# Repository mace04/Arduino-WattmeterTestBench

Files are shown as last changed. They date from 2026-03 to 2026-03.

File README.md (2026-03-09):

# ESP32 Wattmeter Test Bench

A comprehensive motor test bench system built on ESP32, designed for measuring and analyzing the performance of electric motors in RC applications (propellers and EDF units). The system provides both local touchscreen interface and web-based remote control with real-time monitoring capabilities.

I had great problem connecting my HX711 sensor to ESP32 and make it work, so I decided to us an arduino that will read the weight sensor and send the readings to ESP via I2C. For more details see project in [mace04/Arduino-WeightSensor](https://github.com/mace04/Arduino-WeightSensor)

## Project Overview

This test bench measures voltage, current, power consumption, thrust, and monitors motor performance over time. It supports both manual throttle control and automated test sequences with configurable parameters. The dual-core ESP32 handles sensor acquisition and web services concurrently, making it ideal for precision motor testing.

**Key Features:**
- Real-time voltage, current, thrust, and power measurement
- Manual and automated testing modes
- TFT touchscreen interface with multiple screens
- Web-based configuration and monitoring
- Over-the-air firmware updates
- Dual-core processing for responsive operation
- Persistent storage for settings and test profiles

## Main Capabilities

### 1. Motor Testing Modes

#### Manual Mode
- Direct throttle control from analog input or TFT interface
- Real-time sensor data display (voltage, current, thrust, power)
- Energy consumption tracking (mAh)
- Start/stop control with safety interlocks
- Emergency throttle cut via hardware switch

#### Auto Test Mode
- Automated test sequences with 5 phases:
  - Phase 0: Ramp up from 0% to 50% throttle (configurable duration)
  - Phase 1: Hold at 50% throttle (configurable duration)
  - Phase 2: Ramp up from 50% to 100% throttle
  - Phase 3: Hold at 100% throttle
  - Phase 4: Ramp down from 100% to 0%
- Configurable warm-up and phase durations
- Automatic data logging throughout test

### 2. Sensor Measurements

- **Voltage**: 12-bit ADC with calibration and running average filter
- **Current**: 12-bit ADC with calibration and running average filter  
- **Thrust**: I2C weight sensor bridge with configurable scale and offset
- **Power**: Calculated from voltage × current
- **Energy Consumption**: Accumulated mAh over time
- **Elapsed Time**: Test duration timer (mm:ss format)

#### Weight Sensor I2C Protocol
- **Companion Device Project**: [mace04/Arduino-WeightSensor](https://github.com/mace04/Arduino-WeightSensor)
- **I2C Address**: `0x11`
- **Pins**: SDA=`GPIO26`, SCL=`GPIO25`
- **Read Payload**: 4-byte `float` (weight in grams)
- **Calibration Payload**: 8-byte packet `{ float scale, int32_t offset }`
- **Tare Reset Command**: single-byte command `0xA5` (`I2C_CMD_TARE_RESET`)
- **Read Fallback Behavior**: if read payload is incomplete/invalid, firmware returns the last known valid weight

See detailed protocol documentation: [WeightI2Cprotocol.md](WeightI2Cprotocol.md)

### 3. Display Interface (TFT Touchscreen)

- **Main Menu**: Access manual test, auto test, about screen, and profile selection
- **Motor Test Screen**: Real-time data panels showing all sensor readings
- **Calibration Mode**: Guided calibration for voltage, current, and thrust sensors
- **Scale Calibration**: Separate mode for calibrating the load cell
- **Message Boxes**: User notifications and error messages

### 4. Web Interface

Accessible via WiFi network or ESP32 hotspot (fallback mode)

#### Pages:
- **Home (`/`)**: Main menu with navigation links and live event log
- **Settings (`/settings`)**: Configure all system parameters
- **Test Profile (`/testprofile`)**: Define motor specifications
- **Internal Storage (`/spiffs`)**: Browse and view SPIFFS files
- **SD Card (`/sdcard`)**: Access SD card files (if available)
- **Firmware Update (`/update`)**: OTA firmware and filesystem updates

#### Real-time Features:
- **Server-Sent Events (`/events`)**: Live debug, error, and log messages
- **Streaming (`/stream`)**: Real-time sensor data feed
- **File Download**: Download files from SPIFFS or SD card

### 5. Configuration & Settings

All settings stored in `/settings.json` on SPIFFS:

- **WiFi**: SSID and password
- **Voltage Sensor**: Sensitivity (volts per point) and offset
- **Current Sensor**: Sensitivity (volts per point) and offset
- **Thrust Sensor**: Scale and offset values
- **Safety Limits**: Maximum current and thrust thresholds
- **Test Parameters**: Phase duration and warm-up duration

### 6. Safety Features

- **Throttle Cut Switch**: Hardware emergency stop (GPIO 22)
- **Pre-start Checks**: Validates throttle at zero before starting
- **Error Handling**: Comprehensive error messages via web and display
- **I2C Read Validation**: Guards against short/invalid payloads and falls back to last valid reading

## ESP32 GPIO Pin Mapping

### Display & Touch (SPI)
| Function | GPIO | Description |
|---|---|---|
| TFT_MISO | 19 | SPI MISO |
| TFT_MOSI | 23 | SPI MOSI |
| TFT_SCLK | 18 | SPI Clock |
| TFT_CS | 5 | TFT Chip Select |
| TFT_DC | 2 | Data/Command Select |
| TFT_RST | 4 | TFT Reset |
| TOUCH_CS | 15 | Touch Chip Select |
| TOUCH_IRQ | 13 | Touch Interrupt (optional) |

### SD Card (Shared SPI)
| Function | GPIO | Description |
|---|---|---|
| SD_CS | 17 | SD Card Chip Select |
| SD_MOSI | 23 | SPI MOSI (shared) |
| SD_MISO | 19 | SPI MISO (shared) |
| SD_SCLK | 18 | SPI Clock (shared) |

### Sensors (ADC)
| Function | GPIO | ADC Channel | Description |
|---|---|---|---|
| VOLTAGE_SENSOR_PIN | 35 | ADC1_CH7 | Battery voltage measurement |
| CURRENT_SENSOR_PIN | 34 | ADC1_CH6 | Current sensor input |
| THROTTLE_CONTROL_PIN | 36 | ADC1_CH0 | Manual throttle input |

### Motor Control & Sensors
| Function | GPIO | Description |
|---|---|---|
| ESC_OUTPUT_PIN | 21 | PWM output to ESC (1000-2000μs) |
| THROTTLE_CUT_PIN | 22 | Emergency stop switch (INPUT_PULLUP) |
| WEIGHT_I2C_SDA_PIN | 26 | I2C SDA for weight sensor bridge |
| WEIGHT_I2C_SCL_PIN | 25 | I2C SCL for weight sensor bridge |

### Voltage Divider Details
- **Voltage Sensor**: R1=14.98kΩ, R2=2.14kΩ (ratio ~105.295)
- **Current Sensor**: R1=14.86kΩ, R2=13.59kΩ (ratio ~240.350)

## Web Interface Details

### Main Menu (`/` or `/index`)
- Navigation buttons to all major functions
- Real-time event log at bottom (debug/error/info messages)
- Clean grid layout with CSS styling

### Settings Page (`/settings`)
Organized into sections:
- **WiFi Settings**: SSID and password
- **Voltage Sensor**: Sensitivity and offset calibration
- **Current Sensor**: Sensitivity, offset, and maximum current
- **Thrust Sensor**: Scale, offset, and maximum thrust
- **Test Settings**: Phase duration and warm-up time

Settings are saved to SPIFFS and persist across reboots. Success banner shows after saving.

### Test Profile Page (`/testprofile`)
Configure motor under test:
- **Motor Name**: Up to 50 characters (alphanumeric + spaces)
- **Motor Type**: Propeller or EDF (radio button)
- **Propeller Diameter**: 0-150 inches
- **Propeller Pitch**: 1-20 inches (hidden if EDF selected)
- **Battery Cells**: 1-9 cells

Profile saved to `/testprofile.json` on SPIFFS.

### Internal Storage (`/spiffs`)
- Lists all files in SPIFFS filesystem
- Radio buttons for file selection
- View button displays file content (JSON pretty-printed)
- Text area shows file contents

### Firmware Update (`/update`)
- Upload firmware binary (`.bin`)
- Upload filesystem image (SPIFFS)
- Upload type selector: `firmware` or `filesystem`
- Settings automatically backed up and restored during filesystem updates
- Automatic reboot after successful update

### File Download (`/getfile`)
Query parameters:
- `filename`: File to download
- `from`: Either `spiffs` or `sdcard`

### Real-time Streaming (`/stream`)
Returns JSON with current sensor readings:
```json
{
  "voltage": 12.34,
  "current": 5.67,
  "thrust": 890,
  "power": 70,
  "consumption": 123,
  "time": "02:15",
  "throttle": 75
}
```

### Server-Sent Events (`/events`)
Three event types:
- `debug`: Debug messages from system
- `error`: Error notifications
- `log`: General log messages

JavaScript on web pages subscribes to these for live updates.

## Known Issues

### 1. Running Average Not Fully Implemented
**Location**: [sensors.cpp](src/sensors.cpp#L85-L112)

The `readVoltageGpio()` and `readCurrentGpio()` functions have running average code that is commented out with an early return statement. The averaging arrays are allocated but not used.

```cpp
// Current code returns immediately:
return vOut;
// Dead code below calculates average
```

**Impact**: Sensor readings may be noisier than intended.

**Fix**: Remove early returns and enable the averaging logic.

### 2. I2C Weight Sensor Startup Calibration Disabled
**Location**: [sensors.cpp](src/sensors.cpp)

The initial calibration send in `initSensors()` is currently commented out. This means startup may rely on previously retained calibration state in the I2C weight bridge.

**Impact**: Scale/offset may not be explicitly initialized at boot.

**Fix**: Re-enable startup `sendWeightCalibration(settings.getThrustScale(), settings.getThrustOffset())` if deterministic startup calibration is required.

### 3. Static Variables in Auto Test State Machine
**Location**: [motorControl.cpp](src/motorControl.cpp#L143-L211)

Each case in the auto test state machine uses `static bool stageXLogged` variables that are never reset. If auto test is run multiple times, debug messages won't appear after the first run.

**Impact**: Reduced debugging visibility on subsequent auto tests.

**Fix**: Reset static flags in `reset()` or `startAuto()` methods.

### 4. Unreachable Code After Return Statements
**Location**: [sensors.cpp](src/sensors.cpp#L90-L98)

Several functions have unreachable code after return statements (running average calculations).

**Impact**: Compiler warnings and misleading code.

**Fix**: Remove early returns or delete unreachable code.

### 5. Settings Restoration During Filesystem Update
**Location**: [WebServerHandler.cpp](src/WebServerHandler.cpp#L318-L360)

The settings backup/restore during filesystem updates loads settings into RAM but doesn't properly handle the case where SPIFFS is reformatted during update.

**Impact**: Settings may be lost during filesystem updates.

**Fix**: Backup to a file outside SPIFFS or implement more robust restoration.

### 6. SD Card Not Fully Integrated
**Location**: Multiple files

SD card is initialized in pins and main.cpp includes SD.h, but actual SD card functionality appears incomplete. No route handler for `/sdcard` endpoint exists.

**Impact**: SD card file browsing doesn't work from web interface.

**Fix**: Implement `handleFileAccess()` function for SD card access.

## TODO List

### High Priority
- [ ] Fix running average implementation for voltage/current sensors
- [ ] Implement SD card file browser web endpoint (`/sdcard`)
- [ ] Add data logging to SD card during tests (CSV format)
- [ ] Reset static flags in auto test state machine
- [ ] Remove unreachable code after early returns

### Medium Priority
- [ ] Add graphing capabilities to web interface (Chart.js or similar)
- [ ] Implement test result export functionality
- [ ] Add WiFi configuration portal (captive portal on first boot)
- [ ] Create calibration wizard with step-by-step instructions
- [ ] Add authentication to web interface (username/password)
- [ ] Implement motor efficiency calculations (thrust/watt)

### Low Priority
- [ ] Add support for multiple test profiles (save/load by name)
- [ ] Create comparison view for multiple test runs
- [ ] Add temperature sensor monitoring (motor and ESC)
- [ ] Implement RPM measurement (optical sensor)
- [ ] Add battery level estimation (LiPo cell count detection)
- [ ] Create mobile-friendly responsive web design
- [ ] Add WebSocket for bidirectional communication (replace SSE)

### Code Quality
- [x] Document I2C weight protocol in [WeightI2Cprotocol.md](WeightI2Cprotocol.md)
- [ ] Add unit tests for calculation functions
- [ ] Improve error handling and user feedback
- [ ] Document web API endpoints (OpenAPI/Swagger)
- [ ] Add comments to complex functions
- [ ] Implement proper settings validation

### Documentation
- [ ] Create wiring diagram with pin connections
- [ ] Add calibration procedure documentation
- [ ] Write user manual for web interface
- [ ] Document auto test sequence in detail
- [ ] Add troubleshooting guide
- [ ] Create video tutorials

## Dependencies

### PlatformIO Libraries
```ini
lib_deps = 
    ArduinoJson
    bodmer/TFT_eSPI @ ^2.5.43
    paulstoffregen/XPT2046_Touchscreen
    madhephaestus/ESP32Servo
    esp32async/AsyncTCP
    esp32async/ESPAsyncWebServer
```

### Platform
- Framework: Arduino
- Platform: Espressif32
- Board: ESP32 DOIT DevKit v1
- Monitor Speed: 115200 baud

### Partition Scheme
Custom partition: `default_1.5MBapp_spiffs768KB.csv`
- App: ~1.5 MB
- SPIFFS: 768 KB

## File Structure
```
ESP32-WattmeterTestBench/
├── src/                          # Source files
│   ├── main.cpp                  # Main program entry
│   ├── motorControl.cpp          # ESC and throttle control
│   ├── sensors.cpp               # Sensor reading functions
│   ├── Settings.cpp              # Settings management
│   ├── WebServerHandler.cpp      # Web server and API
│   ├── TftMainMenu.cpp           # Main menu screen
│   ├── TftMotorTest.cpp          # Test screen UI
│   ├── TftCalibrate.cpp          # Calibration UI
│   └── [other TFT screens]
├── include/                      # Header files
│   ├── motorControl.h
│   ├── sensors.h
│   ├── Settings.h
│   ├── WebServerHandler.h
│   ├── tft_config.h
│   └── [other headers]
├── data/                         # Web server files (SPIFFS)
│   ├── index.html                # Main menu page
│   ├── settings.html             # Settings page
│   ├── testprofile.html          # Test profile page
│   ├── spiffs.html               # File browser
│   ├── update.html               # OTA update page
│   ├── style.css                 # Shared CSS
│   ├── common.js                 # Shared JavaScript
│   └── index.js
├── schematics/                   # Hardware design files
│   └── WattThrustMeter.fzz       # Fritzing schematic
├── platformio.ini                # PlatformIO configuration
├── increment_version.py          # Auto version script
├── version.txt                   # Current version
├── ESP32 pinout mapping.md       # Pin documentation
└── README.md                     # This file
```

## Getting Started

1. **Hardware Setup**: Wire sensors and display according to pin mapping
2. **Flash Firmware**: Use PlatformIO to build and upload
3. **Upload Filesystem**: Upload SPIFFS image with web files
4. **Configure WiFi**: Edit settings via web interface or serial
5. **Calibrate Sensors**: Use calibration mode (hold throttle cut during boot)
6. **Run Tests**: Select manual or auto mode from TFT or web interface

## License

[Add your license here]

## Author

[Add your name/contact here]

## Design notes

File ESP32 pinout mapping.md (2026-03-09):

### **ESP32 Pin Mapping**
| **Panel Pin** | **ESP32 Pin**  | **Function** | **Purpose** |
|---|---|---|---|
| **LCD_RST** | GPIO16 | Reset | Resets the TFT display |
| **LCD_CS (YP)** | GPIO5 | Chip Select / Y+ (ADC) | Activates TFT module / Y-axis touch input |
| **LCD_RS (XM)** | GPIO4 | Data/Command / X- | Selects between command/data / X-axis touch control |
| **LCD_WR** | GPIO17 | Write Strobe | Signals a write operation to the TFT |
| **LCD_RD** | GPIO21 | Read Strobe | Signals a read operation from the TFT |
| **5V** | 5V | Power | Powers the display |
| **GND** | GND | Ground | Common ground connection |
| **3V3** | 3.3V | Power | Alternative power supply if required |
| **LCD_D0 (XP)** | GPIO12 | Parallel Data Bus / X+ | Pixel data transfer / X-axis touch input |
| **LCD_D1 (YM)** | GPIO13 | Parallel Data Bus / Y- | Pixel data transfer / Y-axis touch control |
| **LCD_D2** | GPIO26 | Parallel Data Bus | Pixel data transfer |
| **LCD_D3** | GPIO25 | Parallel Data Bus | Pixel data transfer |
| **LCD_D4** | GPIO27 | Parallel Data Bus | Pixel data transfer |
| **LCD_D5** | GPIO14 | Parallel Data Bus | Pixel data transfer |
| **LCD_D6** | GPIO33 | Parallel Data Bus | Pixel data transfer |
| **LCD_D7** | GPIO32 | Parallel Data Bus | Pixel data transfer |
| **SD_SS** | GPIO2 | SD Card Chip Select | Activates SD card module |
| **SD_DI (MOSI)** | GPIO23 | SPI MOSI | Sends data to SD card |
| **SD_DO (MISO)** | GPIO19 | SPI MISO | Receives data from SD card |
| **SD_SCK** | GPIO18 | SPI Clock | Synchronizes SD card data transfer |
| **Voltage Sensor**  | GPIO34 | Analog Input (ADC1) | Reads voltage measurements |
| **Current Sensor**  | GPIO35 | Analog Input (ADC1) | Reads current measurements |
| **Throttle Control**| GPIO39 | Analog Input (ADC1) | Reads throttle position |
| **Throttle Cut** | GPIO15 | Digital Input (Unique) | Emergency stop signal |
| **ESC Output (PWM)**| GPIO3 | PWM Output (Unique) | Controls motor speed via ESC |
| **HX711 - DT** | GPIO22 | Weight Sensor Data | Weight measurement input |
| **HX711 - SCK** | GPIO1 | Weight Sensor Clock | Weight sensor clock |

Define mapping to ESP32 devkit v1 for the Starbun TFT LCD Color Touch Panel 3.5" TFT LCD Module 480x320 with the following pins on the panel
    * LCD_RST
    * LCD_CS
    * LCD_RS
    * LCD_WR
    * LCD_RD
    * 5V
    * GND
    * 3V3
    * LCD_D0
    * LCD_D1
    * LCD_D2
    * LCD_D3
    * LCD_D4
    * LCD_D5
    * LCD_D6
    * LCD_D7
    * SD_SS
    * SD_DI
    * SD_DO
    * SD_SCK
Also, the touchscreen uses the below pins from the above defined pins
    * LCD_CS as YP
    * LCD_RS as XM
    * LCD_D1 as YM
    * LCD0 as XP
Finally add the following requirements in the mapping
    * Analog input for voltage sensor
    * Analog input for current sensor
    * Analog input for throttle control
    * Digital input for throttle cut
    * PWM output for ESC control
    * DT for HX711 sensor
    * SCK for HX711 sensor

Define mapping to ESP32 devkit v1 for the 3.5 inch LCD TFT touch display with ili9488 chip Binghe 3.5 inch LCD display touch module with the following pins on the panel
    * VCC
    * GND 
    * CS
    * RESET
    * C/C
    * SDI
    * SCK
    * LED 
    * SDO(MISO)
    * T_CLK
    * TOUCH_CS
    * T_DIN
    * T_OUT
    * TOUCH_IRQ
    * SD_CS
    * SD_MOSI
    * SD_MISO
    * SD_SCK
Also add the following requirements in the mapping
    * Analog input for voltage sensor
    * Analog input for current sensor
    * Analog input for throttle control
    * Digital input for throttle cut
    * PWM output for ESC control
    * DT for HX711 sensor
    * SCK for HX711 sensor

# Sensors 
what is the best board_build.partitions to use for the following
    * Factory app 2MB
    * OTA app 2MB
    * SPIFFS 1.5MB

Create a sensors include file with the following

    Create a function readVoltageSensor to read voltage from the voltage sensor in GPIO34 with the following requirements
        * the pin is connected to a voltage divivder with R1 of 15K and R2 of 2.2K
        * use a running average to smooth readings

    Create a function readCurrentSensor to read voltage from the voltage sensor in GPIO35 with the following requirements
        * the sensor is connected to a ACS758KCB-150B-PFF-T
        * use a running average to smooth readings

    Create a function resetWeightSensor that resets the weight sensor usinh HX711

    Create a function readWeightSensor that reads weight in grams from the weight sensor HX711

Create an motorControl class with the following
    * A function setThrottleCut that sets a global variable for the throttle cut based on a boolean parameter
    * A function setThrottle with the following
        * read the value of throttle control from pin 39
        * if the throttle cut is not set sets the corresponding PWM setting to the esc output in pin 3
        * if the throttle cut is set esc must be set to no throttle
        * returns the throttle control value from pin 39 as a percent
    * create a second function setThottle to set the thottle using a parameter percent value and not from a reading from the THROTTLE_CONTROL_PIN with the rest of requirments the same as the original function
    * a function to get the value fo the throttle cut

Create a new include file to handle settings with the following:
    * The following key value pairs should be defined:
        * SSID name and password as string
        * volts per point for votlage sensor as double with initial value of 0.12790
        * voltage offset as double with initial value of 0.00
        * volts per point for current sensor as double with initial value of 0.02
        * current offset as double with a initial value of - 2.5
        * thrust offset as double with initial value of 0.00
        * maximum current as int with initial value of 100
        * maximum thrust as int with initial value of 4900
        * test phase duration in seconds as int with initial value of 45
    * ablity to read key value pair settings from SPIFFS and return with correct data type for the setting
    * ability to write key value pair settings to SPIFFS usng a correct data type for the setting
    * implement all getters and setters
    * the SPIFF settings files not be opened everytime a read is happening
    * the SPIFF settings file should be refreshed everytime a setter is called
    * include any changes required to platforio.ini for lib_deps

Create a new include file with the following:
    * A function to initialise WiFi connection. If wifi is not connected a hotspot should be created to direct to settings endpoint
    * a function to initialise web server endpoints using the WebServer class for settings, ota, file access to sd card files and realtime streaming of sensor readings. 
    * a function to handle GET settings that will respond with the settings.html from SPIFFS to the connected client
    * a function to handle POST settings. all setting values should be saved to the settings variable in main.cpp
    * a function to hanlde OTA firmware update
    * a function get all files from the SD Card and respond with a full list to the connected client
    * a function to stream sensor readings from sensors.h for voltage, current, weight and cacluated watts in csv to the connected client
    * include any changes required to platforio.ini for lib_deps

create a settings.html with the following requirements
    * use style.css
    * use index.js
    * Title heading on the top of the page of Motor Test Settings 
    * Display settings label and input for each setting defined to be replaced by the handleGetSettings function
    * All string input should be of type text
    * Password input should be of type password
    * All numeric inputs should be of type number
    * All labels should be displayed above the inputs in separate row
    * Settings should be displayed in 2 columns

using settings.html as a template and style.css as a stylsheet, create index.html to display a main menu with the following buttons
    * Settings that links to settings.html
    * Update Firmware that links to update.html
    * SD Card that links to sdcard.html
    * Internal Storage that links to spiffs.html

create an update.html file with the following requirements
    * use style.css
    * Title heading on the top of the page of update firmware
    * Request client to select and input a firmware BIN file 
    * submit with value update

change WebServerHandler files to add capabilitie for OTA firmware update with the following
    * Handle for a GET update endpoint to display the update.htm to connected client
    * Handle for as POST update endpoint that will 
        * be able to and httpupload of the file 
        * when upload is finished perform an update of firmware 
        * determine if the update was a success or failure
        * restart the ESP 

Create a class TftMainMenu for a Starbun Parallel 3.5" TFT LCD Colour Touch Panel with the follwing requirements 
    * Use TFT_eSPI and XPT2046_Touchscreen libraries
    * For UX
        * Background colour set to NAVY
        * Menu options should be buttons that can be selected by touch
        * A menu option for Start Manual Test
        * A menu option for Start Auto Test
        * A menu option for About
        * All buttons should be centered vertically and horizontally within the screen
        * Button text should be centered within the boundaries of the button
        * Button colour should be green with an black outline
        * Buttons colour should changed to red when pressed
        * Button corners should be rounded
    * The class should have the following capabilities
        * accept tft panel and touchscreen as parameters in contructor
        * Determining menu selection should be in separate function 
        * Ability  to change to a different screen using the TftScreenMode enum when a button is pressed. This should instruct the core0Task to call the init method of a different class
        * Introduce a debounce capability to detect continuous press on buttons

Create a class TftUpdate class for a 3.5" TFT LCD Colour Touch Panel with the follwing requirements 
    * Use TFT_eSPI and XPT2046_Touchscreen libraries
    * Accept tft panel as parameter in contructor
    * For UX
        * Background colour set to NAVY
        * A rounded red box appears in the center of the screen 
        * The text "Updating Firmware" is displayed 
        * The text displayed in the box should be centered withing the boundaries of the box

Using TftMainMenu as a template create a class TftAbout for a 3.5" TFT LCD Colour Touch Panel with the following requirements 
    * Use TFT_eSPI and XPT2046_Touchscreen libraries
    * For UX
        * Background colour set to NAVY
        * All text set to white
        * Display the title "Motor Testbench" in bold
        * Display Firmware version
        * Display WiFi name
        * Display IP Address
        * Screen should be split into 6 column and display label in 2nd column as left aligned and value in column 5th column as right aligned
    * The class should have the following capabilities
        * accept tft panel and touchscreen as parameters in contructor
        * The init method should chip select PANEL at the start and TOUCH at the end using the setCS?() function in tft_config files
        * the handleTouch method should check both the TOUCH_IRQ interrupt pin and ts.touch() for a touch  
        * TftAbout should be displayed when the About button in TftMainMenu is pressed
        * TftAbout should display TftMainMenu when any touch is detected anywhere inh the screen        

Using TftMainMenu as a template create a class TftMotorTest for a 3.5" TFT LCD Colour Touch Panel with the following requirements 
    * Use TFT_eSPI and XPT2046_Touchscreen libraries
    * For UX
        * Background colour set to NAVY
        * Create a ribbon on the top in DARKCYAN 40px in height to display the below buttons in green with black text for enabled buttons and grey with white text for diabled buttons and rounded corners
            * A Start button to be enabled on the left side of the screen
            * A Stop button to be disabled on the left side of the screen
            * A Reset button to be enabled on the left side of the screen
            * An Exit button to be enabled on the right side of the screen
        * Create a rectangular at the bottom of the screen in black that spans accross the length and is 30px height as a throttle indicator with the following details:
            * Display the value of throttle as a percent value in White text that is updated everytime the throttle is changed
            * As the throttle increases the rectangular bos is filled from left to right in green between 0% and 49%, amber between 50% and 84% and red between 85% and 100%
        * Between the top ribbon and the bottom throttle indicator split the screen into 3 columns and 2 rows to display panels in yellow with rounded conrners for Volts, Current in amps, Thrust in gr, Power in watts, Consumption in mAh and Time in mm:ss. Each pannel will be displayed as:
            * Recangular with rounded corners 
            * Background colour of yellow with black text
            * Top left of the pannel should display the value type
            * Bottom of pannel should display the value units centered within the boundaries of the pannel
            * Middle of pannel should display the value read in bigger fonts than the other two and updated every time the value changes.
    * The class should have the following capabilities
        * Define enabled and disabled colours for buttons
        * Define state of buttons
        * Accept tft panel, touchscreen and MANUAL or AUTO enum as test type as parameters in contructor
        * An init method to draw the full screen
        * A method to draw buttons with proper colours depending on their state
        * A method to change the state of the button and their colours when
        * A handler to update values on the panels and throttle that is called by the main task in main.cpp every 500ms
        * A method to handleTouch that will the following:
            * Call screenChangeCallback only when Exit button is preased to change to the Main Menu
            * Ignores press of disabled buttons
            * When Start button is pressed, the button becomes disabled and the Stop button is enabled
            * When Stop button is pressed, the button is disabled and the Start button is enabled
            * When Reset button is pressed the Start button is enabled and the Stop button is disabled
            * The Start, Stop and Rest buttons have a private method each to execute code

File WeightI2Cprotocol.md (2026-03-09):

# Weight Sensor I2C Protocol

This document defines the I2C protocol used between the ESP32 firmware and the external weight sensor bridge device.

Companion I2C device implementation: https://github.com/mace04/Arduino-WeightSensor

## Overview

- **Bus mode**: ESP32 is I2C **master**
- **Device address**: `0x11` (`WEIGHT_I2C_ADDRESS`)
- **ESP32 pins**:
  - `SDA = GPIO26` (`WEIGHT_I2C_SDA_PIN`)
  - `SCL = GPIO25` (`WEIGHT_I2C_SCL_PIN`)
- **I2C clock**: `100 kHz`

## Data Types and Endianness

- Floating point values are transmitted as **32-bit IEEE-754 float**.
- Integer offset is transmitted as **signed 32-bit integer** (`int32_t`).
- Multi-byte values are sent as raw in-memory bytes from the ESP32 side.
- Both ends must use compatible byte order and type sizes.

## Message Types

## 1) Weight Read (ESP32 -> Device, then Device -> ESP32)

### Request
ESP32 requests 4 bytes:

- `Wire.requestFrom(0x11, 4)`

### Response payload (4 bytes)

```text
Byte 0..3: float weight_grams
```

### Firmware behavior on receive

- If exactly 4 bytes are returned and value is finite: cache and return new weight.
- If byte count is wrong, stream underruns, or float is non-finite:
  - generate error event (throttled by warning flag)
  - return last known valid weight
  - if no valid value has ever been received, return `0`

## 2) Calibration Write (ESP32 -> Device)

### Purpose
Set calibration parameters used by the weight bridge.

### Payload (8 bytes)

```text
Byte 0..3: float scale
Byte 4..7: int32_t offset
```

### Used by firmware

- `calibrateWeightSensor()` sends default calibration:
  - `scale = 1.0f`
  - `offset = 0`

## 3) Tare Reset Command (ESP32 -> Device)

### Purpose
Request a tare/reset action from the weight bridge.

### Command byte

- `I2C_CMD_TARE_RESET = 0xA5`

### Payload

```text
Byte 0: 0xA5
```

### Used by firmware

- `resetWeightSensor()` sends this command as a single-byte I2C transmission.

## Error Handling Expectations

The device should:

- Respond to read requests with exactly 4 bytes when data is available.
- Gracefully handle malformed/unexpected calibration writes.
- Accept and process `0xA5` tare command idempotently when possible.

The ESP32 firmware currently:

- Validates response length and float sanity (`isfinite`).
- Emits error events on communication/payload failures.
- Uses last-known-value fallback to avoid UI/stream glitches when reads fail intermittently.

## Reference Implementation Mapping

- Protocol constants and declarations: `include/sensors.h`
- I2C send/read logic: `src/sensors.cpp`
  - `sendWeightCalibration(float, int32_t)`
  - `readWeightSensor()`
  - `resetWeightSensor()`

## Suggested Device-Side Contract

For best interoperability, implement the slave-side behavior as:

1. On write of 8 bytes: parse as `{scale, offset}` and apply calibration.
2. On write of 1 byte `0xA5`: perform tare/reset.
3. On master read request of 4 bytes: return latest weight as float grams.
4. Ensure response generation is quick and non-blocking.

## Versioning Note

If protocol changes are introduced later (new commands, CRC, sequence numbers), add a version byte or command frame format to maintain backward compatibility.

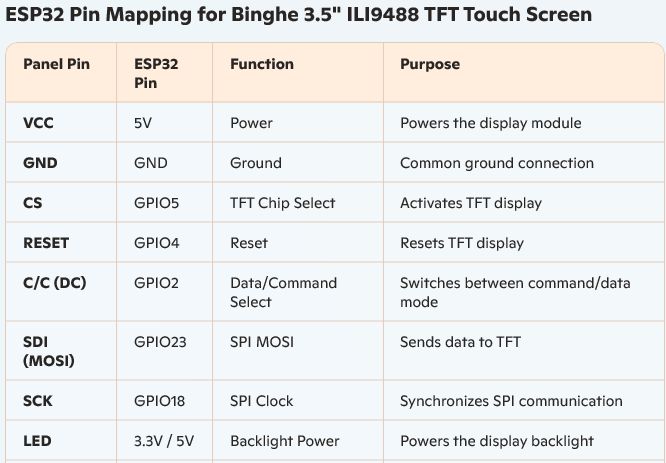
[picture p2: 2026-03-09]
schematics/ESP32 Pin Mapping for Binghe 3.5 ILI9488 TFT Touch Screen.png

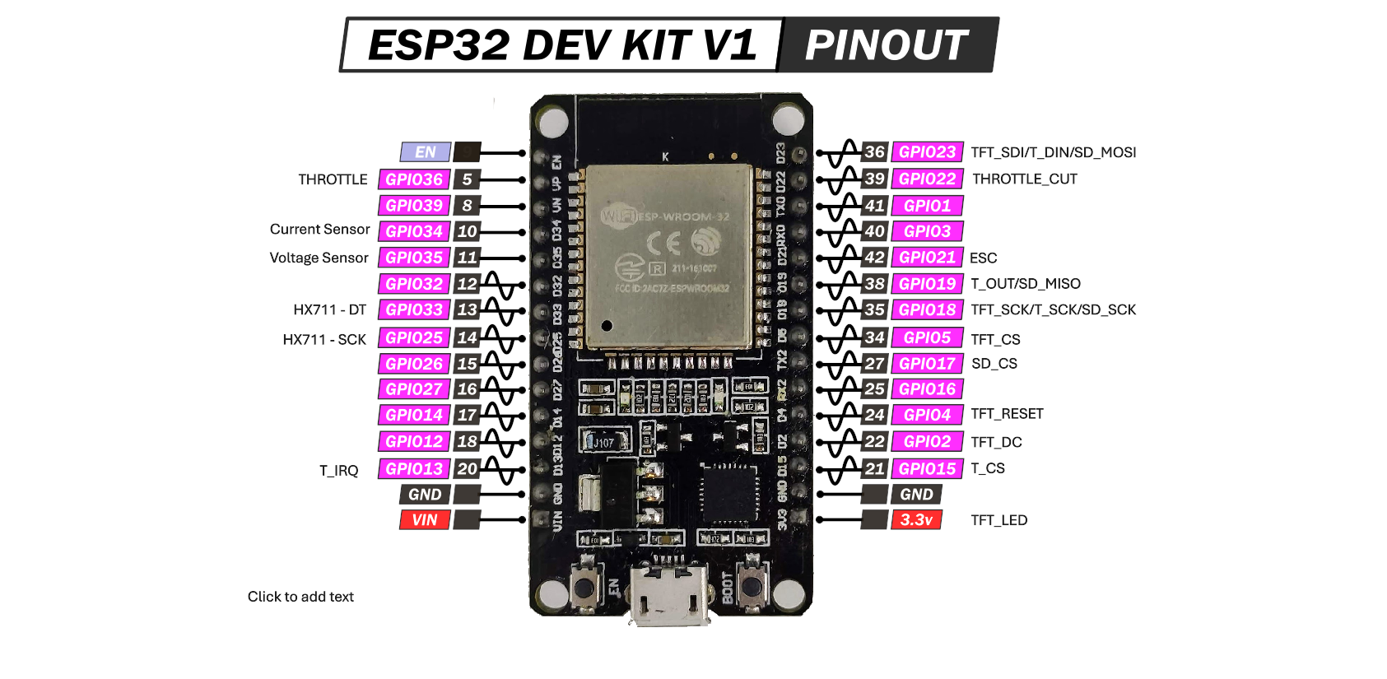
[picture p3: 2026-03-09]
schematics/ESP32-DOIT-DEV-KIT-v1-pinout.png

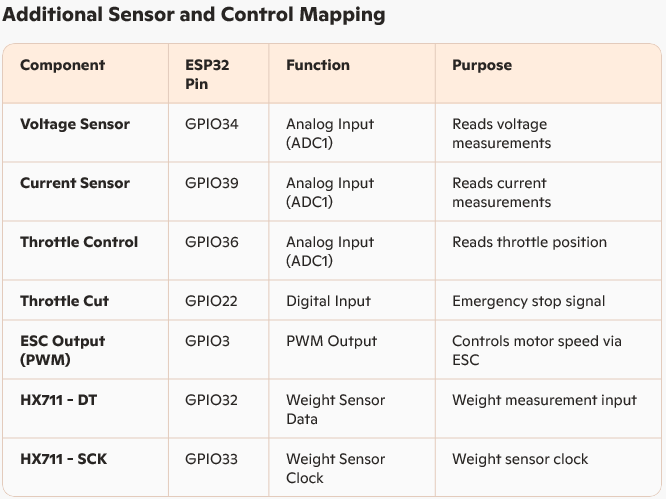
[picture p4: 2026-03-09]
schematics/Additional Sensor and Control Mapping.png

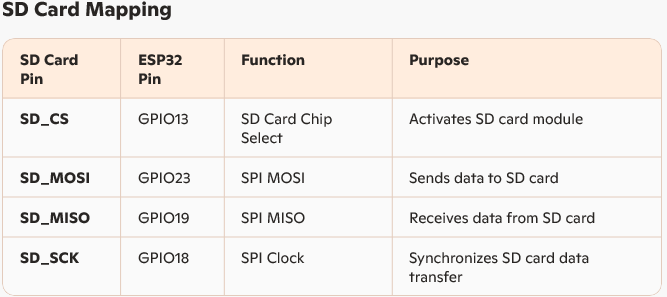
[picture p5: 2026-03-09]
schematics/SD Card Mapping.png

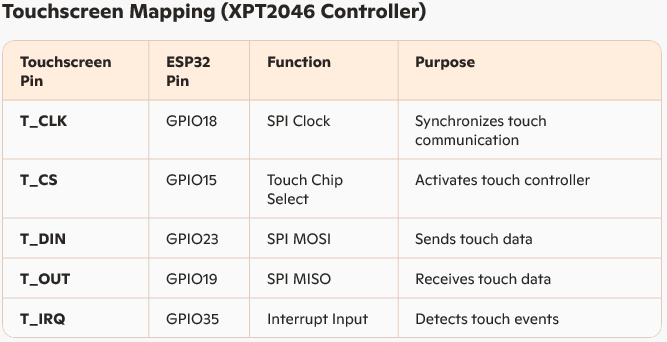
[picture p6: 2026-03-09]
schematics/Touchscreen Mapping (XPT2046 Controller).png

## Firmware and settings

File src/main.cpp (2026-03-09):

#include <Arduino.h>
#include <SD.H>
#include "soc/rtc.h"
#include "sensors.h"
#include "motorControl.h"
#include "Settings.h"
#include "WebServerHandler.h"
#include "tft_config.h"
#include "TftMainMenu.h"
#include "TftAbout.h"
#include "TftMotorTest.h"
#include "TftCalibrate.h"
#include "TftCalibrateScale.h"
#include "TftMessageBox.h"
#include <WiFi.h>

void screenChangeCallback(TftScreenMode screenMode);

Settings settings; // Create an instance of the Settings class
MotorControl motorControl; // Create an instance of the MotorControl class
TFT_eSPI tft = TFT_eSPI();
XPT2046_Touchscreen ts(TOUCH_CS, TOUCH_IRQ); // Touchscreen instance
TftScreenMode currentScreen = MAIN_MENU;
struct Profile testProfile = {"",0,0,0};

float voltage = 0.0; // Variable to store voltage reading
float current = 0.0; // Variable to store current reading
int thrust = 0; // Variable to store thrust reading
int power=0; // Variable to store power reading
float mAh = 0.0; // Variable to store accumulated mAh
bool enterCalibrationMode = false; // Flag to enter calibration mode in Setup
bool calibrateScale = false; // Flag to calibrate ESC in Setup


// Task handles
TaskHandle_t core0TaskHandle = NULL;
TaskHandle_t core1TaskHandle = NULL;

TftMainMenu tftMainMenu(tft, ts, screenChangeCallback);
TftAbout tftAbout(tft, ts, screenChangeCallback);
TftMotorTest tftMotorTest(tft, ts, screenChangeCallback);
TftCalibrate tftCalibrate(tft, ts);
TftCalibrateScale tftCalibrateScale(tft, ts);

// Callback function to handle screen changes
void screenChangeCallback(TftScreenMode screenMode) {
    currentScreen = screenMode;
    if (screenMode == MAIN_MENU) {
        tftMainMenu.init();
    } else if (screenMode == ABOUT) {
        tftAbout.init();
    } else if (screenMode == MANUAL_TEST){
        tftMotorTest.init(MANUAL);
    }
    else if (screenMode == AUTO_TEST){
        tftMotorTest.init(AUTO);
    }
}

// Task running on Core 0
void core0Task(void *parameter) {
    while (true) {
        handleWebServer(); // Handle web server requests
        motorControl.handleControls(); // Handle manual controls
        if (motorControl.isRunning()) {
            if (motorControl.getRunningMode() == MotorControl::RunningMode::AUTO) {
                motorControl.handleAutoTest(); // Handle auto test
            }
            tftMotorTest.Voltage = readVoltageSensor(); // Read voltage sensor
            tftMotorTest.Current = readCurrentSensor(); // Read current sensor
            tftMotorTest.Thrust = readWeightSensor(); // Read thrust sensor
            tftMotorTest.Power = calculatePower(voltage, current); // Calculate power in watts
            tftMotorTest.Consumption = calculateConsumption(current); // Calculate mAh
            tftMotorTest.Time = getElapsedTime(); // Get elapsed time
            tftMotorTest.ThrottlePercent = motorControl.getThrottlePercent(); // Get throttle percentage
       } else{
            tftMotorTest.Voltage = readVoltageSensor(); // Read voltage sensor
            tftMotorTest.Current = readCurrentSensor(); // Read current sensor
            tftMotorTest.Thrust = readWeightSensor(); // Read thrust sensor
            tftMotorTest.Power = 0;
            tftMotorTest.Consumption = 0;
            tftMotorTest.Time = getElapsedTime(); // Get elapsed time
            tftMotorTest.ThrottlePercent = motorControl.getThrottlePercent(); // Get throttle percentage
        }
        delay(10); // Delay to prevent task starvation
    }
}

// Task running on Core 1
void NormalModeTask(void *parameter) {
    while (true) {
        if (isCSActive(TOUCH)) {
            if (currentScreen == MAIN_MENU) {
                tftMainMenu.handleTouch();
            } else if (currentScreen == ABOUT) {
                tftAbout.handleTouch();
            } else if (currentScreen == MANUAL_TEST || currentScreen == AUTO_TEST) {
                tftMotorTest.handleTouch();
            } 
        }
        delay(10); // Delay to prevent task starvation
    }
}

void CalibrationModeTask(void *parameter) {
    while (true) {
        if(calibrateScale && !tftCalibrateScale.calibrationComplete)
            tftCalibrateScale.handle();
        else{
            tftCalibrate.handle();
        }
        
        delay(10); // Delay to prevent task starvation
    }
}

void IRAM_ATTR setCalibrationModeFlag() {
    static bool enterCalibrationModeOnce = false;
    if(enterCalibrationModeOnce) return;
    enterCalibrationMode = true;
    tft.println("Entering Calibration Mode");
    enterCalibrationModeOnce = true;
}

void IRAM_ATTR setCalibrateScaleFlag() {
    static bool enterCalibrateScaleOnce = false;
    if(enterCalibrateScaleOnce) return;
    calibrateScale = true;
    // tft.println("Calibrating Scale");
    tft.setTextColor(TFT_WHITE, TFT_NAVY);
    tft.setTextDatum(MC_DATUM);
    tft.drawString("Calibrating Scale", tft.width() / 2, tft.height() - 20);
    enterCalibrateScaleOnce = true;
}


void setup() {
    // rtc_cpu_freq_config_t config;
    // rtc_clk_cpu_freq_get_config(&config);
    // rtc_clk_cpu_freq_to_config(RTC_CPU_FREQ_80M, &config);
    // rtc_clk_cpu_freq_set_config_fast(&config);

    pinMode(THROTTLE_CUT_PIN, INPUT_PULLUP); // Configure throttle cut pin with pull-up resistor
    attachInterrupt(digitalPinToInterrupt(THROTTLE_CUT_PIN), setCalibrationModeFlag, FALLING);
    delay(20);

    // Initialize serial communication
    Serial.begin(115200);
    Serial.printf("Flash size: %i MB\n", ESP.getFlashChipSize() / (1024 * 1024));
    Serial.println();

    // Initialize CS pins
    pinMode(TFT_CS, OUTPUT);
    pinMode(TOUCH_CS, OUTPUT);
    pinMode(SD_CS, OUTPUT);
    // pinMode(TOUCH_IRQ, INPUT_PULLUP); // Set touch IRQ pin as input with pull-up resistor

    // Set all CS pins to HIGH (disabled)
    digitalWrite(TFT_CS, HIGH);
    digitalWrite(TOUCH_CS, HIGH);
    digitalWrite(SD_CS, HIGH);

    // Initialise TFT touch screen
    tft.init();
    tft.setRotation(3); // Adjust as needed

    // Initialize touchscreen
    setCS(PANEL); // Set CS for TFT panel

    tft.fillScreen(TFT_BLACK);
    // Test display colors
    tft.fillScreen(TFT_RED);
    delay(500);
    tft.fillScreen(TFT_GREEN);
    delay(500);
    tft.fillScreen(TFT_BLUE);
    delay(500);
    tft.setTextSize(2);
    tft.setTextColor(TFT_WHITE, TFT_BLUE);
    Serial.println("TFT Device Initialised");
    if(enterCalibrationMode) {
        tft.println("Entering Calibration Mode");
    } 
    ts.begin();
    tft.println("Touch Device Initialised");
    Serial.println("Touch Device Initialised");
    ts.setRotation(1);    

    // Initialize settings, weight sensor, WiFi, and web server
    // initWeightSensor(HX711_DT_PIN, HX711_SCK_PIN); // Initialize weight sensor
    settings.loadSettings();
    tft.println("Settings Loaded");
    Serial.println("Settings Loaded");

    motorControl.init(settings); // Initialize motor control
    tft.println("Motor Control Initialised");
    Serial.println("Motor Control Initialised");

    initSensors(); // Initialize sensors
    tft.println("Sensors Initialised");
    Serial.println("Sensors Initialised");

    initWiFi(settings.getSSID().c_str(), settings.getPassword().c_str());
    tft.println("WiFi Initialised");
    Serial.println("WiFi Initialised");

    initWebServer(settings);
    tft.println("Web Server Initialised");
    Serial.println("Web Server Initialised");

    Serial.println("Setup complete. Tasks started on both cores.");
    sendDebugEvent("Setup complete. Tasks started on both cores.");
    delay(2000);

    detachInterrupt(digitalPinToInterrupt(THROTTLE_CUT_PIN));

    if(enterCalibrationMode) {
        #ifdef HX711_h
        tft.println("");
        tft.println("");
        tft.println("Calibration Mode");
        attachInterrupt(digitalPinToInterrupt(THROTTLE_CUT_PIN), setCalibrateScaleFlag, FALLING);
        delay(20);
        tft.fillScreen(TFT_NAVY);
        TftMessageBox::info(tft, "Press STOP to calibrate the Weight Sensor");
        delay(5000);
        detachInterrupt(digitalPinToInterrupt(THROTTLE_CUT_PIN));
        #endif
        if (calibrateScale){
            tftCalibrateScale.init(calibrateScale);
        }
        else{
            tftCalibrate.init(calibrateScale);
        }
    }
    else {
        screenChangeCallback(MAIN_MENU);
    }

    // Create tasks for each core
    xTaskCreatePinnedToCore(
        core0Task,          // Task function
        "WebServicesAndSensors",        // Name of the task
        10000,              // Stack size (in bytes)
        NULL,               // Task input parameter
        1,                  // Priority of the task
        &core0TaskHandle,   // Task handle
        0                   // Core to run the task on (Core 0)
    );

    if(enterCalibrationMode) {
        xTaskCreatePinnedToCore(
            CalibrationModeTask,          // Task function
            "CalibrationMode",        // Name of the task
            10000,              // Stack size (in bytes)
            NULL,               // Task input parameter
            1,                  // Priority of the task
            &core1TaskHandle,   // Task handle
            1                   // Core to run the task on (Core 1)
        );
    }
    else {
        xTaskCreatePinnedToCore(
            NormalModeTask,          // Task function
            "NormalMode",        // Name of the task
            10000,              // Stack size (in bytes)
            NULL,               // Task input parameter
            1,                  // Priority of the task
            &core1TaskHandle,   // Task handle
            1                   // Core to run the task on (Core 1)
        );
    }
}

void loop() {
    // The loop function can remain empty as tasks are running on both cores
}

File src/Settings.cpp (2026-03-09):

#include "Settings.h"

Settings::Settings() {
    // Initialize default values
    ssid = "";
    password = "";
    voltsPerPointVoltage = 0.12790;
    voltageOffset = 0.00;
    voltsPerPointCurrent = 0.02;
    currentOffset = -2.5;
    thrustScale = 139.00;
    thrustOffset = 0.00;
    maxCurrent = 100;
    maxThrust = 4900;
    testPhaseDuration = 15;
    testWarmDuration = 5; // Assuming testWarmDuration is defined
}

void Settings::loadSettings() {
    if (!SPIFFS.begin(true)) {
        Serial.println("Failed to mount SPIFFS");
        return;
    }
    readFromSPIFFS();
}
  
void Settings::saveSettings() {
    writeToSPIFFS();
    readFromSPIFFS(); // Read back to verify
}

void Settings::readFromSPIFFS() {
    File file = SPIFFS.open("/settings.json", "r");
    if (!file) {
        Serial.println("Failed to open settings file for reading");
        return;
    }

    size_t size = file.size();
    if (size > 1024) {
        Serial.println("Settings file size is too large");
        return;
    }

    std::unique_ptr<char[]> buf(new char[size]);
    file.readBytes(buf.get(), size);

    JsonDocument doc;
    auto error = deserializeJson(doc, buf.get());
    if (error) {
        Serial.println("Failed to parse settings file");
        return;
    }

    ssid = doc["ssid"] | "";
    password = doc["password"] | "";
    voltsPerPointVoltage = doc["voltsPerPointVoltage"] | 0.12790;
    voltageOffset = doc["voltageOffset"] | 0.00;
    voltsPerPointCurrent = doc["voltsPerPointCurrent"] | 0.02;
    currentOffset = doc["currentOffset"] | -2.5;
    thrustScale = doc["thrustScale"] | 139.00;
    thrustOffset = doc["thrustOffset"] | 0.00;
    maxCurrent = doc["maxCurrent"] | 100;
    maxThrust = doc["maxThrust"] | 4900;
    testPhaseDuration = doc["testPhaseDuration"] | 45; 
    testWarmDuration = doc["testWarmDuration"] | 15; // Assuming testWarmDuration is defined

    file.close();
}

void Settings::writeToSPIFFS() {
    JsonDocument doc;
    doc["ssid"] = ssid;
    doc["password"] = password;
    doc["voltsPerPointVoltage"] = voltsPerPointVoltage;
    doc["voltageOffset"] = voltageOffset;
    doc["voltsPerPointCurrent"] = voltsPerPointCurrent;
    doc["currentOffset"] = currentOffset;
    doc["thrustScale"] = thrustScale;
    doc["thrustOffset"] = thrustOffset;
    doc["maxCurrent"] = maxCurrent;
    doc["maxThrust"] = maxThrust;
    doc["testPhaseDuration"] = testPhaseDuration;
    doc["testWarmDuration"] = testWarmDuration; // Assuming testWarmDuration is defined
    File file = SPIFFS.open("/settings.json", "w");
    if (!file) {
        Serial.println("Failed to open settings file for writing");
        return;
    }

    serializeJson(doc, file);
    file.close();
}

// Getter methods
String Settings::getSSID() { return ssid; }
String Settings::getPassword() { return password; }
float Settings::getVoltsPerPointVoltage() { return voltsPerPointVoltage; }
double Settings::getVoltageOffset() { return voltageOffset; }
float Settings::getVoltsPerPointCurrent() { return voltsPerPointCurrent; }
double Settings::getCurrentOffset() { return currentOffset; }
float Settings::getThrustScale() { return thrustScale; }
double Settings::getThrustOffset() { return thrustOffset; }
int Settings::getMaxCurrent() { return maxCurrent; }
int Settings::getMaxThrust() { return maxThrust; }
int Settings::getTestPhaseDuration() { return testPhaseDuration; }
int Settings::getTestWarmDuration() { return testWarmDuration; } // Assuming testWarmDuration is defined

// Setter methods
void Settings::setSSID(const String& newSSID) { ssid = newSSID; }
void Settings::setPassword(const String& newPassword) { password = newPassword; }
void Settings::setVoltsPerPointVoltage(double value) { voltsPerPointVoltage = value; }
void Settings::setVoltageOffset(double value) { voltageOffset = value; }
void Settings::setVoltsPerPointCurrent(double value) { voltsPerPointCurrent = value; }
void Settings::setCurrentOffset(double value) { currentOffset = value; }
void Settings::setThrustScale(double value) { thrustScale = value; }
void Settings::setThrustOffset(double value) { thrustOffset = value; }
void Settings::setMaxCurrent(int value) { maxCurrent = value; }
void Settings::setMaxThrust(int value) { maxThrust = value; }
void Settings::setTestPhaseDuration(int value) { testPhaseDuration = value; }
void Settings::setTestWarmDuration(int value) { testWarmDuration = value; }

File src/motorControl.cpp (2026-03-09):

#include "motorControl.h"

// Global instance of MotorControl
extern MotorControl motorControl;


MotorControl::MotorControl() {
    throttleCut = false; // Initialize throttle cut to false
    autoTestEnabled = false; // Initialize auto test enabled to false
    running = false; // Initialize running to false
    runningMode = MANUAL; // Default running mode is MANUAL
    ESP32PWM::allocateTimer(0);
    ESP32PWM::allocateTimer(1);
    ESP32PWM::allocateTimer(2);
    ESP32PWM::allocateTimer(3);
}

void MotorControl::init(Settings& settings){
    pinMode(THROTTLE_CUT_PIN, INPUT_PULLUP); // Configure throttle cut pin with pull-up resistor

    warmDuration = settings.getTestWarmDuration(); // Duration for throttle ramp-up/down (in seconds)
    phaseDuration = settings.getTestPhaseDuration(); // Duration for holding throttle levels (in seconds)

    escControl.setPeriodHertz(50);    // standard 50 hz servo
    escControl.attach(ESC_OUTPUT_PIN, MIN_THROTTLE, MAX_THROTTLE); // attaches the servo on pin 18 to the servo object
    escControl.writeMicroseconds(MIN_THROTTLE); // Set initial ESC signal to minimum throttle
    Serial.println("ESC Microseconds: " + String(escControl.readMicroseconds())); // Debugging output
    sendDebugEvent("ESC Microseconds: " + String(escControl.readMicroseconds()));
}

void MotorControl::reset() {
    // Reset throttle cut
    setThrottleCut(false);

    // Reset throttle to 0
    setThrottle(0);

    // Reset running state
    setRunning(false);

    // Reset ESC output
    escControl.writeMicroseconds(MIN_THROTTLE); // Set initial ESC signal to minimum throttle

    if (getRunningMode() == AUTO) {
        state = 0; // State machine to track the current phase
        stateStartTime = 0; // Start time for the current phase
        stateCurrentThrottle = 0; // Current throttle percentage
    }

    resetTimer(); // Assuming resetTimer() is defined elsewhere

    Serial.println("MotorControl has been reset to default state.");
    sendDebugEvent("MotorControl has been reset to default state.");
}

bool MotorControl::startManual(String& error, bool calibrate) {
    if (throttleCut) {
        error = "Cannot start motor. Throttle cut is enabled.";
        return false;
    }

    if (isThrottle()) {
        error = "Cannot start motor. Throttle is not 0.";
        return false;
    }

    // Set running mode to MANUAL
    setRunningMode(MANUAL);

    // Set running state to true
    setRunning(!calibrate);

    // Initialize throttle to 0
    setThrottle(0);

    // Start Timer
    startTimer(); // Assuming startTimer() is defined elsewhere

    Serial.println("Motor started in MANUAL mode.");
    sendDebugEvent("Motor started in MANUAL mode.");

    return true;
}

bool MotorControl::startAuto(String& error) {
    if (throttleCut) {
        error = "Cannot start motor. Throttle cut is enabled.";
        return false;
    }
    // Set running mode to MANUAL
    setRunningMode(AUTO);

    warmDuration = settings.getTestWarmDuration(); // Duration for throttle ramp-up/down (in seconds)
    phaseDuration = settings.getTestPhaseDuration(); // Duration for holding throttle levels (in seconds)

    // Set running state to true
    setRunning(true);

    // Initialize throttle to 0
    setThrottle(0);

    // Start Timer
    startTimer(); // Assuming startTimer() is defined elsewhere

    state = 0; // State machine to track the current phase
    stateStartTime = 0; // Start time for the current phase
    stateCurrentThrottle = 0; // Current throttle percentage

    Serial.println("Motor started in AUTO mode.");
    sendDebugEvent("Motor started in AUTO mode.");

    return true;
}

void MotorControl::handleControls(){
    if(digitalRead(THROTTLE_CUT_PIN) == LOW){
        setThrottle(0);       // Set throttle to 0
        setThrottleCut(true); // Set throttleCut to true
        setRunning(false);    // Set running to false    
        Serial.println("Throttle cut activated! Motor stopped.");
        sendDebugEvent("Throttle cut activated! Motor stopped.");
    }
    static int lastThrottle = 0;
    if (!getThrottleCut() && getRunningMode() == MotorControl::MANUAL) {
        setThrottle();
        // motorControl.setRunning(true); // Set running to true
        if (lastThrottle != getThrottlePercent() && isRunning()) {
            lastThrottle = getThrottlePercent();
            Serial.println("Throttle change: " + String(lastThrottle) + "%");
            sendDebugEvent("Throttle change: " + String(lastThrottle) + "%");
        }
    }
}

void MotorControl::handleAutoTest() {
    unsigned long currentTime = millis(); // Get the current time

    switch (state) {
        case 0: // Ramp up from 0% to 50%
            static bool stage0Logged = false;
            if (!stage0Logged) {
                Serial.println("Auto Test State 0: Ramping up to 50%");
                sendDebugEvent("Auto Test State 0: Ramping up to 50%");
                stage0Logged = true;
            }
            if (stateStartTime == 0) stateStartTime = currentTime; // Initialize start time
            if (stateCurrentThrottle < 50) {
                int elapsed = currentTime - stateStartTime;
                stateCurrentThrottle = map(elapsed, 0, warmDuration * 1000, 0, 50); // Calculate throttle percentage
                setThrottle(stateCurrentThrottle);
            } else {
                stateCurrentThrottle = 50;
                setThrottle(stateCurrentThrottle);
                stateStartTime = 0; // Reset start time
                state = 1; // Move to the next state
            }
            break;

        case 1: // Hold at 50%
            static bool stage1Logged = false;
            if (!stage1Logged) {
                Serial.println("Auto Test State 1: Holding at 50%");
                sendDebugEvent("Auto Test State 1: Holding at 50%");
                stage1Logged = true;
            }
            if (stateStartTime == 0) stateStartTime = currentTime; // Initialize start time
            if (currentTime - stateStartTime >= phaseDuration * 1000) {
                stateStartTime = 0; // Reset start time
                state = 2; // Move to the next state
            }
            break;
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

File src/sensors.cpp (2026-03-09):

#include "sensors.h"
#include <math.h>

// Declare the global settings object from main.cpp
extern Settings settings;
esp_adc_cal_characteristics_t adc_characteristics;

struct WeightCalibrationPacket {
    float scale;
    int32_t offset;
};

static_assert(sizeof(WeightCalibrationPacket) == 8, "WeightCalibrationPacket must be 8 bytes");

 bool sendWeightCalibration(float scale, int32_t offset) {
    WeightCalibrationPacket packet{scale, offset};

    Wire.beginTransmission(WEIGHT_I2C_ADDRESS);
    Serial.println("Sending weight calibration command with scale: " + String(scale) + " and offset: " + String(offset));
    const uint8_t* raw = reinterpret_cast<const uint8_t*>(&packet);
    Wire.write(raw, sizeof(packet));
    Serial.println("Weight calibration command sent, awaiting response...");
    uint8_t status = Wire.endTransmission();
    Serial.println("Weight calibration command response received, status: " + String(status));

    if (status != 0) {
        sendErrorEvent("Weight I2C calibration write failed");
        Serial.print(F("[TX] weight calibration failed, status="));
        Serial.println(status);
        return false;
    }
    Serial.println("Weight sensor calibration command sent.");
    return true;
}

// Variables for running averages
float voltageReadings[AVERAGE_WINDOW_SIZE] = {0};
uint32_t voltageGpioReadings[AVERAGE_WINDOW_SIZE] = {0};
float currentReadings[AVERAGE_WINDOW_SIZE] = {0};
uint32_t currentGpioReadings[AVERAGE_WINDOW_SIZE] = {0};
int voltageIndex = 0;
int voltageGpioIndex = 0;
int currentIndex = 0;
int currentGpioIndex = 0;

// Global variables to track running consumption and elapsed time
float totalConsumption; // Total consumption in mAh
unsigned long lastConsumptionUpdateTime; // Last time consumption was updated

// Global variables for the timer
bool timerRunning = false;               // Tracks whether the timer is running
unsigned long timerStartTime = 0;        // Stores the start time of the timer
unsigned long timerElapsedTime = 0;      // Stores the elapsed time when paused

void initSensors() {
    // Initialize ADC
    pinMode(CURRENT_SENSOR_PIN, INPUT); // Set current sensor pin as input    
    adc1_config_width(ADC_WIDTH);
    adc1_config_channel_atten(ADC_VOLTAGE_SENSOR_CHANNEL, ADC_ATTEN);
    adc1_config_channel_atten(ADC_CURRENT_SENSOR_CHANNEL, ADC_ATTEN);
    adc1_config_channel_atten(ADC_THTOTTLE_CHANNEL, ADC_ATTEN);
    // Characterize the ADC
    esp_adc_cal_characterize(ADC_UNIT_1, ADC_ATTEN, ADC_WIDTH, DEFAULT_VREF, &adc_characteristics);

    Wire.begin(WEIGHT_I2C_SDA_PIN, WEIGHT_I2C_SCL_PIN, 100000);
    delay(100);

    // if (sendWeightCalibration(settings.getThrustScale(), static_cast<int32_t>(settings.getThrustOffset()))) {
    //     sendDebugEvent("Weight I2C sensor initialized.");
    // }
}

void calibrateWeightSensor() {
    // Resets to default calibration state, matching harness behavior
    sendWeightCalibration(1.0f, 0);
    resetWeightSensor();
}

uint32_t readVoltageGpio(){
    uint32_t adc_reading = adc1_get_raw(ADC_VOLTAGE_SENSOR_CHANNEL);
    uint32_t vOut = esp_adc_cal_raw_to_voltage(adc_reading, &adc_characteristics);
    // Update running average
    // voltageGpioReadings[voltageIndex] = vOut;
    return vOut;
    voltageGpioIndex = (voltageIndex + 1) % AVERAGE_WINDOW_SIZE;

    float sum = 0;
    for (int i = 0; i < AVERAGE_WINDOW_SIZE; i++) {
        sum += voltageGpioReadings[i];
    }
    return sum / AVERAGE_WINDOW_SIZE;
}

uint32_t readCurrentGpio(){
    uint32_t adc_reading = adc1_get_raw(ADC_CURRENT_SENSOR_CHANNEL);
    uint32_t vOut = esp_adc_cal_raw_to_voltage(adc_reading, &adc_characteristics);
    // Update running average
    // currentGpioReadings[currentIndex] = vOut;
    return vOut;
    currentGpioIndex = (currentIndex + 1) % AVERAGE_WINDOW_SIZE;

    float sum = 0;
    for (int i = 0; i < AVERAGE_WINDOW_SIZE; i++) {
        sum += currentGpioReadings[i];
    }
    return sum / AVERAGE_WINDOW_SIZE;
}

// Function to read and smooth voltage sensor readings
float readVoltageSensor() {

    uint32_t adc_reading = adc1_get_raw(ADC_VOLTAGE_SENSOR_CHANNEL);
    float vOut = esp_adc_cal_raw_to_voltage(adc_reading, &adc_characteristics) / 1000.00;
    float voltage = vOut * settings.getVoltsPerPointVoltage() + settings.getVoltageOffset(); // Convert ADC value to voltage

    // Update running average
    voltageReadings[voltageIndex] = voltage;
    voltageIndex = (voltageIndex + 1) % AVERAGE_WINDOW_SIZE;

    float sum = 0;
    for (int i = 0; i < AVERAGE_WINDOW_SIZE; i++) {
        sum += voltageReadings[i];
    }
    return sum / AVERAGE_WINDOW_SIZE;
}

// Function to read and smooth current sensor readings
float readCurrentSensor() {
    
    uint32_t adc_reading = adc1_get_raw(ADC_CURRENT_SENSOR_CHANNEL);
    float vOut = esp_adc_cal_raw_to_voltage(adc_reading, &adc_characteristics) / 1000.00;
    float current = vOut * settings.getVoltsPerPointCurrent() + settings.getCurrentOffset(); // Convert ADC value to voltage

    // Update running average
    currentReadings[currentIndex] = current;
    currentIndex = (currentIndex + 1) % AVERAGE_WINDOW_SIZE;

    float sum = 0;
    for (int i = 0; i < AVERAGE_WINDOW_SIZE; i++) {
        sum += currentReadings[i];
    }
    return sum / AVERAGE_WINDOW_SIZE;
}

// Function to reset the weight sensor via I2C calibration packet
void resetWeightSensor() {
    Wire.beginTransmission(WEIGHT_I2C_ADDRESS);
    Wire.write(I2C_CMD_TARE_RESET);
    uint8_t status = Wire.endTransmission();
    if (status != 0) {
        sendErrorEvent("Weight I2C tare reset command failed");
        Serial.print(F("[TX] weight tare reset failed, status="));
        Serial.println(status);
    }
    Serial.println("Weight sensor tare reset command sent.");
}
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

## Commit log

2025-04-08 Schematics and default config
2025-04-12 Operational Web Server
    [FTBPQQTH1YOKSNV.xlsx]
2025-04-12 Adjust sensor calculations using settings
2025-04-12 Created interrupts to manage throttle control and cut. Introduced flags for is running, and running mode
2025-04-12 Get sensor reading during running tests
2025-04-13 Crerated init method to be called at setup and avoid unexpected exceptions whencreating interrupts during bootup
    [motorControl.cpp, motorControl.h]
2025-04-15 Changed pin mappingto ESP32 to fit the board pins
2025-04-17 changes in mapping to reflect the correct esp32 board
2025-04-19 Changed pins for sensors and peripherals to avoid conficts
    [motorControl.h, sensors.h]
2025-04-19 New functions to control chip select and which is currently active
2025-04-19 Hand chip select correclty between TFT and Touchscreen sensor
2025-04-20 Center button text and set correct colouring
2025-04-21 Added screen for Manual and Auto motor test. No sensors reading just yet
2025-04-21 Added pin mapping tables
2025-04-21 Added method to start manual test and stop and reset tests
    [motorControl.cpp, motorControl.h]
2025-04-23 Added a panels property and timer interrupt to update screen easier
2025-04-23 Stop access to upload page if motor test is running
2025-04-24 Fill throttle inidcator withproper colour depending the reading
2025-04-24 Make sure throttle boarder is not removed
2025-04-24 Draw border of throttle indicator
2025-04-25 Added functions to calculate power and consumption
2025-04-25 Added functions to calculate power and consumption as well as timer functions
2025-04-25 Reset ans pause timer when needed duing a test
    [motorControl.cpp]
2025-04-26 Added warm up/down time setting for throttle
2025-05-01 Removed old pin mapping file
2025-05-02 Read actual PWM value to returned as throttle percent
2025-05-06 Change pin numbers for sensors
2025-05-07 Display volts and amps per poinbt to 6 decimal places
2025-05-07 Calcuilate voltage and current using per point setting. More efficient
2025-10-03 Added pin mapping picture of ESP32
2025-10-03 Changes to pin mappings in ESP32
2025-10-05 Latest correct pin mapping to ESP32
2025-10-05 Final version after pin mapping changes and adding the abvility to set a test profile
2025-10-08 Display an alert when STOP button is pressed
2025-10-09 Removed all interrupts to avoid crashes and display error messages on screen
    [TftMotorTest.cpp, TftMotorTest.h, main.cpp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]
2025-10-10 Incresed size of error message box to fit all messages
    [TftMotorTest.cpp]
2025-10-19 ESP32 partition for this project
    [default_1.5MBapp_spiffs768KB.csv]
2025-10-24 Use ESP32Servo Library to control ESC
2025-10-25 Added Calibration mode and screen
2025-10-25 ESC Pin moved to GPIO21
2025-10-26 Added Return to Home button on all pages
2025-10-26 Set Voltage and Current Scales and Offsets to millivolts for better precision
2025-11-03 Added weight sensor scale value in Settings
2025-11-03 Manage weight sensor scale settings in web server
2025-11-03 Manage Weight Sensor Scale settings in webserver
2025-11-03 Added capabilities to calibrate weight sensor.
    *** This still requires testing
2025-11-04 Use TftMessageBox to display error messages
    [TftMotorTest.cpp, TftMotorTest.h]
2025-11-08 Display GPIO voltage for sensors
2025-11-08 Use full CPU frequency and allow to calibrate Weight sensor only of HX711 has been included
2025-11-08 Use ADC raw reads to get throttle value
2025-11-08 Use ADC raw reads to get throttle values
2025-11-09 Use raw ADC readings for Sensors
2025-11-12 Corrected precision of current setting values entered in Settings page
2025-11-12 Do not set the isRunning flag if in Calibration screens
2025-11-12 Weight sensor always return an integer in grams
2025-11-17 Migrate from WebServer to AsyncWebServer and create an event source for debug printing
2026-01-23 Add README for ESP32 Wattmeter Test Bench project
    This README provides an overview of the ESP32 Wattmeter Test Bench project, detailing hardware and software capabilities, including motor control, sensor integration, and user interfaces.
2026-02-22 Change HX711 DT pin to GPIO26
2026-02-22 Log staged test with debug events
2026-02-22 Add README with project overview and pin mapping
2026-03-01 Set thrust scale value correctly
    [Settings.cpp]
2026-03-03 remove debug serial print
2026-03-04 replace HX711 with an I2C device
    [WebServerHandler.cpp, sensors.cpp, sensors.h]
2026-03-04 reference connection to project https://github.com/mace04/Arduino-WeightSensor
2026-03-09 Added error messages to Serial
    [sensors.cpp]
